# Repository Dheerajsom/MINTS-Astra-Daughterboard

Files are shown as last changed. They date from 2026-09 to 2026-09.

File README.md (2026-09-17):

# MINTS-Astra-Daughterboard

120 × 80 mm, four-layer EC Sense gas-sensor I2C daughterboard, revision B. The project contains the editable KiCad schematic and PCB, local component libraries, manufacturing files, assembly data, source scripts, reference documents, and verification reports.

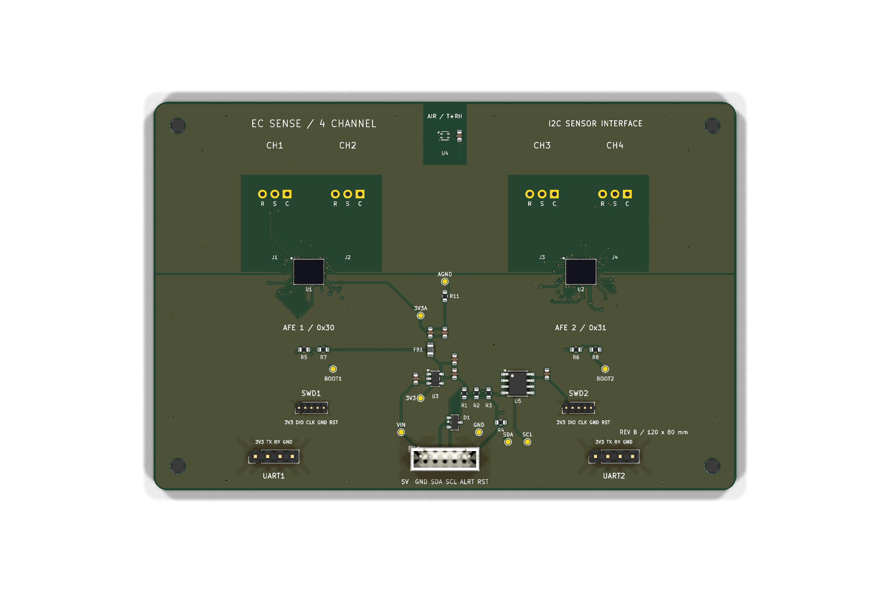
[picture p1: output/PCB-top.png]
Completed PCB, top view


## Open the design

Open [`ECSense_4CH_I2C.kicad_pro`](ECSense_4CH_I2C.kicad_pro) in KiCad 10. The project uses local footprint and 3D-model paths. The schematic and board retain their original `ECSense_4CH_I2C` filenames so project references remain intact.

Read [`PCB_README.md`](PCB_README.md) for electrical corrections, connector pinouts, assembly requirements, and bring-up instructions.

## Files

| Location | Contents |
| --- | --- |
| [`ECSense_4CH_I2C.kicad_pcb`](ECSense_4CH_I2C.kicad_pcb) | Completed routed PCB |
| [`ECSense_4CH_I2C.kicad_sch`](ECSense_4CH_I2C.kicad_sch) | Revision B schematic |
| [`ECGAS.pretty/`](ECGAS.pretty), [`libraries/`](libraries), [`models/`](models) | Local footprints and available 3D models |
| [`manufacturing/gerbers/`](manufacturing/gerbers) | Four copper layers, masks, silkscreens, pastes, outline, and drill files |
| [`manufacturing/assembly/`](manufacturing/assembly) | BOM and placement CSVs |
| [`Fabrication and assembly drawings`](output/pdf/Fabrication_and_assembly.pdf) | Mechanical, assembly, and drill drawings |
| [`Schematic PDF`](ECSense_4CH_I2C.pdf) | Printable schematic |
| [`output/`](output) | Board previews and final drawings |
| [`verification/`](verification) | Final checks plus development and routing records |
| [`scripts/`](scripts) | Construction, routing, and export scripts |
| [`sources/`](sources) | Manufacturer reference documents |

Download the [`complete project ZIP`](EC-Sense-120x80-Project.zip) or [`fabrication Gerbers ZIP`](manufacturing/EC-Sense-120x80-Gerbers.zip). The complete project ZIP is the compact release package; this repository also includes supporting development files.

## Verification and fabrication

The final KiCad 10.0.5 checks recorded **0 DRC violations, 0 unconnected items, 0 schematic parity discrepancies, and 0 ERC violations**. See [`final-drc.rpt`](verification/final-drc.rpt), [`final-erc.rpt`](verification/final-erc.rpt), and [`release-summary.json`](verification/release-summary.json). Earlier reports in `verification/` record intermediate work; the `final-*` reports describe the delivered board.

Specify four copper layers, nominal 1.6 mm FR-4, ENIG, and a fabricator supporting **0.075 mm trace/clearance and 0.20 mm via drills with 0.40 mm pads**. Read the full [fabrication notes](manufacturing/FABRICATION_NOTES.txt) before ordering.

This is a hardware prototype. Application firmware, gas-sensor calibration, and physical bench testing are required before use.

## Development records

The saved revision B KiCad project and `PCB_README.md` are authoritative. `DESIGN.md`, the original generator, and intermediate routing files document earlier stages. Construction scripts can overwrite completed routing; review them before running them. Local automatic backups, temporary files, editor state, and caches are ignored by Git.

Third-party KiCad library notices are included in [`libraries/LICENSE.md`](libraries/LICENSE.md) and [`models/kicad/LICENSE.md`](models/kicad/LICENSE.md).

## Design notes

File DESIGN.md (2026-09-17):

> **Revision B PCB update:** Read [PCB_README.md](PCB_README.md) for corrected pinouts, component values, socket selection, power range and bring-up requirements. Several assumptions in this original architecture note were incorrect. The corrected schematic and PCB are authoritative.

# 4-Channel EC Sense Gas Sensor Board with a Single I²C Bus

Design note + KiCad schematic for a custom carrier that takes four **bare ES1 3-pin
electrochemical sensors** and presents all their data on one I²C bus.

Source datasheets (in this folder):
`ES1-AG1-200-01 All Gas Sensor_Datasheet_V1.4_20250306.pdf`,
`TB600B&C-IAQ_Datasheet_V3.0_20250904.pdf`,
`EC Sense Product List_V1.9_20250409.pdf`.

---

## 1. What the datasheets actually give you

### 1.1 Bare sensor — ES1 series (the 3-pin part)

From the ES1-AG1-200-01 datasheet:

| Parameter | Value | Design consequence |
|---|---|---|
| Operating principle | Amperometric, **3-electrode** | Needs a potentiostat, not just an ADC |
| Pins (bottom view) | **C, S, R** in line — Counter, Sense (working), Reference | 3 pins, 2.54 mm pitch, Ø0.4 mm, body ~11.5 × 11.5 × 5.6 mm |
| Bias voltage | **0 mV** | V_BIAS = V_ZERO for this part; other gases may differ |
| Recommended load resistor | **100 Ω** | Set the AFE's R_LOAD to 100 Ω |
| Sensitivity | **40 nA/ppm ± 10** (CO cal), 55 nA/ppm ± 15 (isobutene cal) | 200 ppm FS → **8 µA**; 1000 ppm overload → 40 µA |
| Zero current | **± 100 nA** | = ±2.5 ppm equivalent. Zeroing in clean air is mandatory, not optional |
| Resolution | 0.1 ppm quoted "16-bit ADC" | 0.1 ppm ≈ 4 nA — well inside a decent TIA+ADC |
| Response | T50 < 10 s, T90 < 30 s | 1–4 Hz output rate is plenty; use the rest for averaging |
| Warm-up | < 60 s | |
| Temperature curve | ≈ **4 nA/ppm at −40 °C → ≈ 51 nA/ppm at +50 °C** | ~12× swing. **On-board temperature measurement and compensation is compulsory** |
| Long-term drift | < 5 %/year, life > 3 years | Recalibration/cartridge-swap plan needed |
| Storage | 0–20 °C (optimum 4–6 °C), 12 months | Keep spares refrigerated; ship with the electrode shorting clip fitted |

Two things worth flagging before you commit to a BOM:

- **AG1 "All Gas" is deliberately non-selective.** The cross-sensitivity table shows
  CO reads 105 ppm for a 100 ppm test, H₂ reads 625 ppm for 2000 ppm, AsH₃ reads 4 ppm
  for a 1 ppm calculated concentration, and NO₂/O₃ read *negative*. Four AG1 sensors will
  not give you four gases — populate the four sockets with gas-specific ES1 parts
  (CO, H₂S, NO₂, SO₂, NH₃, O₃, HCHO, …) from the product list.
- **O₂ (`01-ES1-O2-25%-01`) is electrically different** from the amperometric parts.
  If you need O₂, treat it as a separate channel variant, not a drop-in.

### 1.2 Ready-made module — TB600B/C (the "breakout board")

The TB600B&C is EC Sense's own breakout: the ES1 sensor + a microcontroller + a
temperature/humidity sensor + a flash chip holding the factory calibration, on a
23 × 25.5 × 9.5 mm board with a 4-pin cable.

| Parameter | Value |
|---|---|
| Output | UART TTL 3.3 V **or** I²C 3.3 V (separate part numbers, `…-I2C-01`) |
| I²C pinout | VCC = red, GND = black, **SDA = yellow, SCL = green** |
| **I²C clock** | **≤ 20 kHz** |
| Supply | 3.3–5.5 V, 5 V recommended; ~3.4–6.2 mA (I²C, LED off / peak) |
| Sleep | 0.9 mA @ 5 V |
| On-board T/RH | ±0.2 °C, ±2 % RH |
| Protocol | Q&A mode by default, switchable to active-upload |

**Why this pushes you toward your own board.** The datasheet publishes no address-select
pin and no address-configuration command, and the bus is limited to 20 kHz. Multiple
TB600-I2C modules on one bus will therefore collide. Your options with the stock modules
are a **TCA9548A I²C mux** (one module per channel) or an **LTC4316 address translator**
per module — both of which mean you are still paying for four microcontrollers, four
T/RH sensors and ~100 mm² each, to end up with a 20 kHz bus.

> **Plan B, if you want something working next week:** 4 × `04-TB600x-<gas>-<range>-I2C-01`
> behind a TCA9548A, 5 V rail, host talks to 0x70 then to the module. Zero analog design
> risk. Take this path for the first prototype if the science matters more than the board.

The rest of this document is **Plan A**: your own carrier around the bare ES1.

---

## 2. What the front end has to do

Per channel:

1. Hold the **reference electrode** at a programmed potential relative to the working
   electrode (0 mV for most EC Sense parts) — i.e. a potentiostat with a control
   amplifier driving the counter electrode.
2. Convert the working-electrode current to voltage with a **transimpedance amplifier**,
   with a settable R_LOAD of 100 Ω in series with the working electrode.
3. Digitise it with enough resolution that the **LSB is well under the sensor noise**.

Numbers, using 40 nA/ppm:

| Sensor | FS current | R_TIA | TIA FS | ADC LSB (16-bit over ±0.9 V) | ppm/LSB |
|---|---|---|---|---|---|
| ES1-AG1-**200** | 8.0 µA | 100 kΩ | 0.80 V | 27.5 µV → 0.275 nA | **0.0069 ppm** |
| ES1-AG1-**10** | 400 nA | 512 kΩ | 0.205 V | 27.5 µV → 0.054 nA | **0.0013 ppm** |
| ES1-CO-**1000** | 40 µA | 20 kΩ | 0.80 V | 27.5 µV → 1.4 nA | 0.034 ppm |

So a 16-bit ADC behind a programmable TIA comfortably beats the datasheet's own
0.01 ppm / 0.1 ppm resolution figures. **The limit is not the LSB — it is the ±100 nA
zero current, the 5 %/year drift and the 12× temperature coefficient.** Budget your
effort accordingly: the analog design is the easy part, the calibration is not.

Since R_TIA is switchable at runtime on the chosen part, implement **autoranging**:
drop to a low gain when a channel saturates (the ES1 overload range is 5× full scale)
and report the range in the status register.

---

## 3. IC options

| Role | Part | Key numbers | Verdict |
|---|---|---|---|
| **Potentiostat + ADC + MCU, 2 ch** | **ADuCM355** (ADI) | 2 potentiostats, LPTIA R_TIA 1 k–512 kΩ, R_LOAD 10/30/50/100/1.5k/3k/3.5k Ω, 16-bit 400 kSPS ADC, dual 12-bit bias DACs 0.2–2.4 V, EIS 0.016 Hz–200 kHz, Cortex-M3 26 MHz / 128 kB flash, UART+I²C+SPI, 72-LGA 6×5 mm, 2.8–3.6 V, 4.75–5.2 mA active / 3 µA hibernate | **Chosen.** One part does the whole channel, each device is its own I²C target, and EIS gives you sensor-health diagnostics for free |
| Potentiostat AFE, **4 ch**, no MCU | MAX30134 (ADI/Maxim) | 4 DC channels + 1 EIS channel, 4 × 16-bit current ADCs, 4 × 12-bit DACs, 3.5 µA bias current, 25-bump WLP 2.93 × 2.93 mm, ~$5.45/1k, **SPI only** | Strongest alternative — one chip for all four channels, half the cost. Costs you an external MCU and 0.4 mm-pitch WLP assembly |
| Same analog core, AFE only | AD5941 / AD5940 | SPI, pair with STM32G0/L4/RP2350 | Use if you already have an MCU you like and want ADI's analog core |
| Cheap single-channel potentiostat | TI **LMP91000** / LMP91002 | R_TIA 2.75 k–350 kΩ, internal bias 1–24 % of V_REF, I²C **for configuration only**, analog V_OUT, fixed address 0x48 with an **MENB** pin so several can share a bus | The classic budget option; needs an external ADC and 4 chip-selects |
| Precision I²C ADC (if using LMP91000) | TI ADS122C04 (24-bit, 2 diff ch, PGA), TI ADS1115 (16-bit, 4 ch, 4 addr), Microchip MCP3424 (18-bit, 4 ch, 8 addr) | | ADS122C04 if you care about noise, ADS1115 if you care about price |
| Discrete potentiostat | MCP6V51 (5 µV offset), LTC6078, ADA4505-2, LMP7721 (3 fA I_B), ADA4530-1 (fA) | | Only if you want full control of the loop and low-leakage input |
| I²C mux (address collisions) | TCA9548A / PCA9548A | 8 channels, 0x70–0x77 | Required for the TB600-I2C route |
| I²C address translator | LTC4316 | remaps a fixed-address target | Alternative to a mux |
| Level translation | PCA9306, TXS0102 | | If the host is 1.8 V |
| Bus extension | LTC4311 (active pull-up), PCA9515A | | If the sensor head is on a cable |
| T / RH | **SHT45-AD1B** (0x44), SHT40, or TMP117 | ±0.1 °C / ±1.0 % RH | Mandatory for compensation |
| ID + cal store | **24AA02E48** (0x50, EUI-48 at 0xFA) | | Board serial + per-sensor cal blob |
| Analog LDO | **ADP151AUJZ-3.3** | 9 µV_rms, 200 mA | Clean rail for the AFE |
| ESD | PESD3V3L2BT, TPD2E007 | | On SDA/SCL |
| Sensor socket | Mill-Max **0350 / 0305** series press-fit receptacles, or a 3-way SIP strip (Mill-Max 801/851 series, Preci-Dip 801-87-003) | accept 0.30–0.51 mm pins | Confirm against the Ø0.4 mm ES1 pin |

### Why ADuCM355 over MAX30134 here

You asked for a smart node per sensor, which the ADuCM355 gives you directly: firmware,
calibration and linearisation live next to the analog, the host sees clean ppm numbers,
and each device is an independent I²C target so a channel failure does not take the bus
down. It is also a hand-solderable LGA rather than a 0.4 mm WLP. The trade is cost
(~2 × ADuCM355 vs 1 × MAX30134) and firmware effort — you are writing an I²C target
driver, not just reading registers.

---

## 4. Chosen architecture

```
   ES1 socket J1 ──C/S/R──┐
                          ├── ADuCM355 U1  (pot 0, pot 1)  ──┐
   ES1 socket J2 ──C/S/R──┘        I²C target 0x30           │
                                                             ├── SDA / SCL ── host (J5)
   ES1 socket J3 ──C/S/R──┐                                  │      + /ALERT, /RESET
                          ├── ADuCM355 U2  (pot 0, pot 1)  ──┤
   ES1 socket J4 ──C/S/R──┘        I²C target 0x31           │
                                                             │
                     SHT45 (0x44) ───────────────────────────┤
                     24AA02E48 (0x50) ───────────────────────┘
```

- Both ADuCM355 run **the same firmware image**; each reads a strap resistor on **P2.4**
  at boot (U1 → 0 Ω to GND → 0x30, U2 → 10 kΩ to +3V3 → 0x31).
- One shared open-drain **/ALERT** (GPIO0 on both devices) for threshold alarms, so the
  host does not have to poll.
- **/RESET** is bussed to both devices and brought out to the host connector.
- Programming: SWD per device (J6, J7); **BM/P1.1** pulled up with a test point —
  pulling it low during reset drops the part into a loop so a bad image can be erased
  over SWD. UART on J8/J9 for logging and the serial bootloader.
- Analog rail **+3V3A** is ferrite-isolated from the digital +3V3; **AGND** and **GND**
  meet at a single 0 Ω (R11) under U1.
- **RCAL = 200 Ω, 0.1 %, ≤10 ppm/°C** per device (between RCAL0 and RCAL1) — this is the
  reference the EIS engine calibrates against.

### Per-channel passives (all four channels identical)

| Part | Value | Function |
|---|---|---|
| C_CE | 100 nF | CE ↔ CAP_POT, potentiostat loop compensation |
| C_RC | 100 nF | between RCx_0 and RCx_1, LPTIA filter |
| C_LPF | 4.7 µF | on AIN4_LPF0 / AIN7_LPF1 |
| C_VBIAS | 100 nF | VBIAS decoupling |
| C_VZERO | 100 nF (DNP) | optional, fit per ADI reference design |
| 3 × 22 pF C0G | — | CE / SE / RE to AGND, at the socket, EMC |
| JP (DNP) | — | SE–RE shorting jumper for storage/transport only |

---

## 5. Firmware: suggested I²C register map

8-bit register address, auto-increment, MSB-first, repeated-start for reads.

| Addr | R/W | Bytes | Contents |
|---|---|---|---|
| 0x00 | R | 1 | `WHO_AM_I` = 0xEC |
| 0x01 | R | 1 | `STATUS`: bit0 ch0 ready, bit1 ch1 ready, bit2 ch0 overrange, bit3 ch1 overrange, bit4 warm-up, bit7 fault |
| 0x02 | RW | 1 | `CTRL`: bit0 ch0 enable, bit1 ch1 enable, bit2 start EIS, bit6 sleep, bit7 soft reset |
| 0x03 | RW | 1 | `ODR` (0 = 1 Hz, 1 = 2 Hz, 2 = 4 Hz) |
| 0x10 | R | 4 | CH0 electrode current, int32, **pA** |
| 0x14 | R | 4 | CH0 concentration, int32, **ppb** (temperature-compensated) |
| 0x18 | R | 4 | CH1 electrode current, int32, pA |
| 0x1C | R | 4 | CH1 concentration, int32, ppb |
| 0x20 | R | 2 | Die temperature, int16, 0.01 °C |
| 0x22 | RW | 2 | Ambient temperature written by host (or read from SHT45), int16, 0.01 °C |
| 0x24 | RW | 2 | Ambient RH, uint16, 0.01 %RH |
| 0x30 | RW | 1 | CH0 R_TIA index (0 = auto) |
| 0x31 | RW | 1 | CH1 R_TIA index |
| 0x32 | RW | 2 | CH0 V_BIAS, uint16, DAC code |
| 0x34 | RW | 2 | CH1 V_BIAS |
| 0x40 | RW | 16 | CH0 sensor ID string |
| 0x50 | RW | 4 | CH0 sensitivity, nA/ppm × 1000 |
| 0x54 | RW | 4 | CH0 zero current, pA |
| 0x58 | RW | 4 | CH0 temperature-compensation polynomial coefficients |
| 0x70 | R | 8 | Last EIS result: R_s, C_dl (sensor-health indicator) |
| 0x7E | RW | 1 | `SAVE_CAL` — write 0xA5 to commit cal to flash |

Temperature compensation: store the ES1 curve as a 3rd-order polynomial in T normalised
to 25 °C, `S(T) = S₂₅ · (a₀ + a₁·ΔT + a₂·ΔT² + a₃·ΔT³)`, fitted to the curve on page 3 of
the ES1 datasheet, then refined against your own chamber data. Do **not** use a single
%/°C coefficient — the curve is strongly non-linear below 0 °C.

---

## 6. Layout rules that actually matter

The working-electrode node carries hundreds of picoamps to a few microamps. Leakage,
not noise, is what will ruin it.

1. **Guard ring** around every SE net and its via/pad, driven at V_ZERO (not AGND), on
   both the top layer and the layer directly beneath.
2. Keep SE traces **short (< 15 mm), on one layer, no vias**. Route CE and RE beside
   them, never crossing a digital net.
3. **No solder-mask opening** under the sockets other than the pads. Assemble with
   no-clean flux and clean anyway; ionic residue between SE and AGND at 10¹¹ Ω is a
   0.03 ppm offset.
4. 4-layer stack: L1 AFE + signal, L2 solid GND, L3 +3V3 / +3V3A (split, not overlapping
   the AFE), L4 digital.
5. Do **not** route I²C, SWD or the DC-DC flying-cap nets under the AFE section of U1/U2.
6. AGND and DGND join at **one** point (R11) under the device; AGND pour covers only the
   AFE corner.
7. Put the **SHT45 in the middle of the four sockets**, thermally coupled to them, with a
   routed slot isolating it from the LDO and the MCU dies. It is measuring *the sensors'*
   temperature, not the board's.
8. Keep the LDO and any heat source at the opposite end of the board. A 1 °C gradient
   across the sensor cluster is a ~2.5 % reading error at room temperature.
9. Conformal-coat the board **except** the socket area and the sensor apertures. Never
   let alcohol, acetone or strong solvent near the sensors (explicit datasheet warning).

---

## 7. BOM (4 channels)

| Qty | Ref | Part | Description |
|---|---|---|---|
| 2 | U1, U2 | ADUCM355BCCZ | Dual potentiostat + 16-bit ADC + Cortex-M3, 72-LGA |
| 1 | U3 | ADP151AUJZ-3.3 | 3.3 V 200 mA ultra-low-noise LDO, TSOT-23-5 |
| 1 | U4 | SHT45-AD1B | T/RH sensor, I²C 0x44 |
| 1 | U5 | 24AA02E48T-I/SN | 2 kbit EEPROM with EUI-48, I²C 0x50 |
| 4 | J1–J4 | 3 × Mill-Max 0350-series receptacle (or 1 × 3-way SIP socket) | EC Sense ES1 socket, 2.54 mm, Ø0.4 mm pin |
| 1 | J5 | JST PH B6B-PH-K | Host: VIN, GND, SDA, SCL, /ALERT, /RESET |
| 2 | J6, J7 | 1×5 1.27 mm header | SWD |
| 2 | J8, J9 | 1×4 2.54 mm header | UART / serial bootloader |
| 1 | D1 | PESD3V3L2BT | ESD array on SDA/SCL |
| 1 | FB1 | 600 Ω @ 100 MHz, 0805 | +3V3 → +3V3A |
| 2 | R (RCAL) | 200 Ω, 0.1 %, ≤10 ppm/°C | EIS calibration |
| 2 | R | 2.2 kΩ | I²C pull-ups |
| 3 | R | 10 kΩ | /ALERT, /RESET, U2 address strap |
| 2 | R | 10 kΩ | BM pull-ups |
| 1 | R | 0 Ω | U1 address strap (→ 0x30) |
| 1 | R11 | 0 Ω | AGND–GND single-point tie |
| 12 | C | 22 pF C0G | Electrode EMC filters (3 per channel) |
| 8 | C | 100 nF X7R | C_CE, C_VBIAS (2 per channel) |
| 4 | C | 100 nF X7R | C_RC (1 per channel) |
| 4 | C | 4.7 µF X7R | C_LPF (1 per channel) |
| 4 | C | 100 nF (DNP) | C_VZERO |
| ~20 | C | 100 nF / 1 µF / 4.7 µF | Supply, regulator and DC-DC decoupling — **values per ADuCM355 datasheet Applications Information** |
| 4 | JP1–JP4 | Solder jumper (DNP) | SE–RE storage short |

---

## 8. KiCad 10 project

Everything is written in the **native KiCad 10 format** — not a KiCad 7 file that
KiCad 10 upgrades on open. The schematic is `version 20260306`
(`generator_version "10.0"`), the symbol library is `version 20251024`, and the project
file uses `meta.version 3` / `net_settings.meta.version 5`. All of it was produced and
checked with KiCad **10.0.6**.

### `ECSense_4CH_I2C/`

| File | What it is |
|---|---|
| `ECSense_4CH_I2C.kicad_pro` | Project file, `Default` / `SENSOR` / `POWER` net classes pre-created |
| `ECSense_4CH_I2C.kicad_sch` | A1 schematic, 198 symbols |
| `ECGAS.kicad_sym` | The 19 custom symbols as a real, editable library |
| `sym-lib-table` | Registers `ECGAS` against `${KIPRJMOD}/ECGAS.kicad_sym` |
| `fp-lib-table` | Registers `ECGAS.pretty` for the two custom footprints |
| `ECGAS.pretty/README.md` | Dimensions and guidance for the two footprints you still have to draw |
| `ECSense_4CH_I2C.pdf` / `.svg` | Schematic plots, exported by KiCad |
| `ECSense_4CH_I2C.net` | KiCad netlist |
| `ECSense_4CH_I2C-bom.csv` | BOM, exported by KiCad |
| `erc.rpt` | The ERC report as it stands |

Build scripts, at the top level:

| File | What it is |
|---|---|
| `gen_sch.py` | Generates the schematic — edit the constants at the top to change channel count, spacing or net names |
| `verify_sch.py` | Connectivity checker: duplicate refdes, dangling labels/wires, single-pin nets, off-grid points, **and T-junctions** |
| `make_symlib.py` | Extracts the embedded symbols into `ECGAS.kicad_sym` |
| `build_kicad10.sh` | Runs the whole chain: generate → check → extract library → upgrade to KiCad 10 → ERC + PDF + SVG + netlist + BOM |

Rebuild with:

```sh
KICAD_CLI=/path/to/kicad-cli ./build_kicad10.sh
```

`gen_sch.py` writes the older s-expression dialect and `build_kicad10.sh` calls
`kicad-cli sch upgrade` / `sym upgrade` to convert — so the format conversion is always
done by KiCad itself rather than by hand.

### Two real shorts that KiCad 10's ERC caught

Running proper ERC found bugs that a syntax check would never have shown. Both were the
same mistake: **a wire routed straight through another wire's endpoint**, which KiCad
treats as a connection.

1. **The entire I²C bus was shorted to GND.** At J5, the GND pin's drop wire ran down
   past the SDA and SCL stubs at exactly the x they ended on. SDA, SCL and GND became
   one net — the board would have been dead on arrival with no obvious cause.
2. **AGND was shorted to GND at both ADuCM355s.** The AGND rail dropped onto the DGND
   rail's horizontal run, merging the analog and digital grounds and making the R11
   single-point tie meaningless — which would have quietly undone the grounding scheme
   in section 6.
3. A third instance at the EEPROM: the `WP` pull-down ran through the SDA and SCL stubs.

`verify_sch.py` now models T-junctions (a point lying in the *interior* of a wire, not
just at its endpoints), so this class of error is caught before KiCad ever sees the file.

### Validation actually performed (KiCad 10.0.6)

```
kicad-cli sch upgrade          -> version 20260306, generator_version 10.0
kicad-cli sym upgrade          -> version 20251024, generator_version 10.0
kicad-cli sch erc              -> 6 violations, ALL of them the two footprints
                                  still to be drawn (4 x ES1 socket, 2 x ADuCM355 LGA).
                                  Zero pin_to_pin, zero multiple_net_names,
                                  zero power_pin_not_driven, zero dangling.
kicad-cli sch export netlist   -> 83 nets, every one with >= 2 nodes
kicad-cli sch export pdf/svg   -> OK
kicad-cli sch export bom       -> OK
verify_sch.py                  -> no duplicate refdes, no dangling labels or wires,
                                  no single-pin nets, 0 T-junctions, all on 1.27 mm grid
```

Netlist spot-check, confirming the buses are separate and the sensor wiring is right:

```
SDA       7  D1.1  J5.3  R1.2  U1.H5  U2.H5  U4.1  U5.5
SCL       7  D1.3  J5.4  R2.2  U1.J5  U2.J5  U4.4  U5.6
GND      29   (separate from AGND)
AGND     41   (separate from GND, tied only through R11)
+3V3A     7  C36.1 C37.1 FB1.2 U1.F11 U1.G2 U2.F11 U2.G2
~{ALERT}  4  J5.5  R3.2  U1.G10 U2.G10
/CH1_CE   4  C1.1  C4.1  J1.1(C)  U1.A1(CE0)
/CH4_SE   4  C26.1 J4.2(S) JP4.1  U2.A9(SE1)
```

## 9. Verify before you fabricate

1. **ADuCM355 pinout.** The pin numbers in the schematic were transcribed from the
   Rev. C datasheet pin table. Two assignments (B1 = RE0, B2 = VZERO0) were reconstructed
   from the symmetry of the channel-1 pins, not read directly. **Check all 72 pins against
   the official PDF and the EVAL-ADUCM355QSPZ reference schematic.**
2. **DC-DC and regulator capacitors.** VDCDC_CAP1P/1N/2P/2N/CAPOUT, AVDD_REG, DVDD_REG,
   DVDD_REG_AD values in the schematic are placeholders. Take them from the datasheet.
3. **ES1 socket.** Confirm the Ø0.4 mm pin diameter and 2.54 mm pitch against the
   mechanical drawing of *your* part numbers, and against the socket's pin-acceptance range.
   Then draw `ECGAS:EC_Sense_ES1_3pin_2.54mm` and `ECGAS:ADuCM355_LGA-72_6x5mm` — these are
   the only two footprints not resolved by the standard KiCad 10 libraries, and the only
   two ERC violations left in `erc.rpt`. See `ECGAS.pretty/README.md`.
4. **Bias per gas.** The ES1-AG1 is 0 mV. Confirm with EC Sense for each gas variant you
   intend to use before fixing the V_BIAS default in firmware.
5. **I²C target mode.** Confirm the ADuCM355 I²C peripheral supports clock stretching in
   target mode at the speed your host runs, and that your host tolerates it.
6. **Bench check the TIA before trusting it.** Drive a known current into a socket
   (a precision voltage source through a 1 GΩ resistor gives clean nanoamps) and verify
   gain and linearity at each R_TIA setting. Then zero in clean air / N₂ and span with
   certified gas.

---

## Sources

- [ADuCM355 product page, Analog Devices](https://www.analog.com/en/products/aducm355.html)
- [ADuCM355 datasheet (Rev. C)](https://www.analog.com/media/en/technical-documentation/data-sheets/aducm355.pdf)
- [ADuCM355 Hardware Reference Manual UG-1262](https://www.analog.com/media/en/technical-documentation/user-guides/aducm355-hardware-reference-manual-ug-1262.pdf)
- [MAX30131/MAX30132/MAX30134 electrochemical sensor AFEs](https://www.analog.com/en/products/max30134.html)
- [MAX30131/32/34 datasheet](https://www.analog.com/media/en/technical-documentation/data-sheets/max30131-max30132-max30134.pdf)
- [AD5941 analog front end](https://www.analog.com/en/products/ad5941.html)
- [AD5940 analog front end](https://www.analog.com/en/products/ad5940.html)
- [AN-2058: ADuCM355 User Bootloader](https://www.analog.com/en/resources/app-notes/an-2058.html)
- EC Sense `ES1-AG1-200-01 All Gas Sensor_Datasheet_V1.4_20250306.pdf` (local)
- EC Sense `TB600B&C-IAQ_Datasheet_V3.0_20250904.pdf` (local)
- EC Sense `EC Sense Product List_V1.9_20250409.pdf` (local)

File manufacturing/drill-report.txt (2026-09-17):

Drill report for ECSense_4CH_I2C.kicad_pcb
Created on 2026-09-16T20:36:38

Copper Layer Stackup:
    =============================================================
    L1 :  F.Cu                      front
    L2 :  In1.Cu                    in1
    L3 :  In2.Cu                    in2
    L4 :  B.Cu                      back

Drill file 'ECSense_4CH_I2C-PTH.drl' contains
    plated through holes:
    =============================================================
    T1  0.200mm  0.0079"  (161 holes))
    T2  0.300mm  0.0118"  (19 holes))
    T3  0.650mm  0.0256"  (10 holes))
    T4  0.750mm  0.0295"  (6 holes))
    T5  1.000mm  0.0394"  (20 holes))

    Total plated holes count 216

Drill file 'ECSense_4CH_I2C-NPTH.drl' contains
    unplated through holes:
    =============================================================
    T1  3.200mm  0.1260"  (4 holes))

    Total unplated holes count 4

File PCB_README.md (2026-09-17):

# EC Sense four-channel I2C PCB — revision B

120 × 80 mm outline, R3 corners, four M3 mounting holes on a 110 × 70 mm pattern. Four copper layers, nominal 1.6 mm FR-4. This is a hardware prototype: the ADuCM355 devices require application firmware and each installed gas sensor requires calibration. Design-rule checking is not a substitute for a powered bench test.

Open `ECSense_4CH_I2C.kicad_pro` in KiCad 10. The PCB, corrected schematic, footprint libraries, manufacturing outputs and verification reports are supplied together. The original schematic and generator are preserved in the working folder's `.history/pre-pcb*`, outside the release archive.

## Completed layout and checks

Final KiCad 10.0.5 checks: **0 DRC violations, 0 unconnected items, 0 schematic parity discrepancies, and 0 ERC violations**. No individual DRC exclusions are used. The checked board contains 109 footprints (96 schematic components, 4 mounting holes and 9 test pads), 1,309 track segments and 180 through vias. Check reports are in `verification/final-drc.*` and `verification/final-erc.*`.

The four layers, from top to bottom, are F.Cu (components/signals/ground), In1.Cu (ground with local escape routing), In2.Cu (power pours/signals), and B.Cu (passives/signals/ground). Analog sensor regions have surface copper keepouts; the temperature/humidity sensor is away from the regulator. Analog and digital grounds meet through R11. Ground stitching connects the surface pours to the inner ground layer.

Deliverables:

- `ECSense_4CH_I2C.kicad_pro`, `.kicad_sch`, `.kicad_pcb`: editable project and design.
- `manufacturing/gerbers/`: four copper layers, masks, silkscreens, pastes, board profile, separate plated/nonplated drill files, and Gerber job file.
- `manufacturing/assembly/`: current BOM and placement CSVs. JP1-JP4 are the only DNP items; all capacitors are fitted.
- `output/pdf/Fabrication_and_assembly.pdf`: mechanical, front/back assembly and drill drawings.
- `ECSense_4CH_I2C.pdf`: updated revision B schematic.
- `output/PCB-top.png` and `output/PCB-bottom.png`: views of the completed layout.
- `manufacturing/EC-Sense-120x80-Gerbers.zip`: fabrication files only.
- `EC-Sense-120x80-Project.zip`: editable design, local libraries, outputs and final checks.

The final KiCad files are authoritative. Scripts in the working folder's `scripts/` record construction and routing iterations; running them again can replace completed routing. These iteration scripts are not included in the release archive.

## Electrical corrections made before layout

The original schematic contained errors beyond the missing footprints:

- U1/U2 channel 0: CE0 is B1; RE0 is A1.
- U4 SHT45: SDA=1, SCL=2, VDD=3, GND=4.
- D1 PESD3V3L2BT: signal pins 1/2, common ground pin 3.
- U1/U2 AVDD_DD (G2) now uses the digital 3.3 V rail as required by the pin table.
- Shared ALERT moved from GPIO0 to GPIO1 (H10). GPIO0 drives high after reset and is unsuitable for the original wired connection. Firmware must emulate open drain: assert low, release by selecting input; never drive high.
- Reference/regulator capacitors and DC/DC flying capacitors now follow ADuCM355 Rev C. VZERO capacitors are populated.
- Added one local 100 nF bypass per ADuCM355 supply pin, plus EEPROM bypass.
- 24AA02E48 pins 1/2/3/7 are marked NC, rather than presenting unused pins as address/write-protect controls.
- VIN is specified as 4.0–5.5 V, nominal 5 V, to allow headroom for the 3.3 V LDO.

## Manufacturing and assembly

Order 4 copper layers, nominal 1.6 mm FR-4, ENIG, solder mask and silkscreen on both sides. No controlled-impedance requirement is specified. The fabricator must support **0.075 mm (approximately 3 mil) minimum trace/clearance, 0.20 mm finished via drills with 0.40 mm pads and 0.10 mm annular rings**. Stitching vias use 0.30 mm drills / 0.60 mm pads. Minimum hole-to-hole spacing is 0.20 mm and copper-to-board-edge clearance is 0.30 mm. The 0.5 mm LGA package requires fine tracks near the processors; ordinary 6/6 mil service is insufficient. Use tented signal vias and inspect the LGA joints after reflow. Discuss the 0.25 mm LGA lands and an approximately 80 µm stencil with the assembler. Surface-mounted parts are on both sides. The board uses ordinary through vias, with no blind/buried vias or via-in-pad process.

All manufacturing and placement outputs use the same absolute KiCad origin. The outline centerline extends from (50, 50) to (170, 130) mm; the line width is a drawing stroke, not extra board material. The four 3.2 mm nonplated mounting holes are at (55,55), (165,55), (55,125), and (165,125) mm. The outer dimensions are exactly 120 x 80 mm, with 3 mm corner radii. Drill and placement outputs follow their file-format axis conventions. The assembly PDF shows the bottom side mirrored for viewing from below; do not mirror the Gerbers.

J1–J4 each accept **three Mill-Max 0548-0-15-15-21-27-10-0 receptacles**. Their #21 contact accepts 0.381–0.559 mm pins; the ES1 pins are 0.40 ±0.01 mm. Footprint holes are 1.00 mm finished plated diameter (manufacturer minimum 0.9144 mm), with 1.8 mm pads and 2.54 mm pitch. C/S/R is mirrored from the sensor's bottom-view drawing into the PCB top view. **The earlier suggestions of Mill-Max 0350 and 0305 are unsuitable for these small sensor pins.**

The sensor drawing does not dimension the pin-row offset within the body. A conservative 14 × 24 mm component courtyard reserves the full possible body envelope around the pin row; no guessed offset is needed for PCB fit. The 3D socket representation is illustrative, not a mating-part inspection model. Insert the gas sensors after soldering and cleaning. Do not expose the sensor apertures or SHT45 to solvents or conformal coating.

C1–C3, C9–C11, C17–C19 and C25–C27: C0G/NP0. Other small capacitors: X7R, preferably 10 V or higher; check effective capacitance under DC bias. R9/R10: 200 Ω, 0.1%, ≤10 ppm/°C. Fit all capacitors. Leave JP1–JP4 open during operation; they are only storage/transport shorts. R11 is the sole AGND–GND connection and must be populated.

## Connectors and bring-up

| Connector | Pin order |
|---|---|
| J5, JST PH 6-pin host | 1 VIN, 2 GND, 3 SDA, 4 SCL, 5 ALERT, 6 RESET |
| J6/J7, 1.27 mm SWD | 1 3V3 reference, 2 SWDIO, 3 SWCLK, 4 GND, 5 RESET |
| J8/J9, 2.54 mm UART | 1 3V3 reference, 2 MCU TX, 3 MCU RX, 4 GND |

All bus/debug signals are **3.3 V logic**. Supply through J5; the 3V3 debug pins are voltage references, not an additional power input. Program U1 and U2 independently using SWD. Their default addresses 0x30 and 0x31 are a firmware convention selected by the P2.4 straps, not fixed hardware addresses. U4 uses 0x44; U5 uses 0x50. BOOT test pads allow recovery by holding the corresponding BM pin low during reset.

Power up initially with a current-limited 5 V supply and no gas sensors. Check 3V3/3V3A and internal regulated/reference voltages, debug access, I2C, and the ALERT release state. Configure the potentiostats and gas-specific bias before insertion. Verify current measurement with a precision current source, then perform clean-air zero and certified-gas span calibration. Firmware, calibrated ppm conversion, environmental qualification and physical bench testing are not included in this PCB deliverable.

## Source drawings

- [Analog Devices ADuCM355 Rev C, pinout and recommended components](https://www.analog.com/media/en/technical-documentation/data-sheets/ADuCM355.pdf), pp. 20–23 and 26–28.
- [Sensirion SHT4x data sheet](https://sensirion.com/resource/datasheet/sht4x).
- [Nexperia PESD3V3L2BT](https://assets.nexperia.com/documents/data-sheet/PESD3V3L2BT.pdf).
- [Microchip 24AA02E48](https://ww1.microchip.com/downloads/en/DeviceDoc/22124C.pdf).
- [EC Sense ES1 mechanical drawing](https://ecsense.com/wp-content/uploads/2021/01/ES1-AG1-200-01-All-Gas-Sensor_Datasheet_V1.4_20250306.pdf).
- [Mill-Max receptacle catalog, p. 157](https://www.mill-max.com/sites/default/files/external/catalog/2020-03/153-201_0.pdf).

The earlier working-folder `DESIGN.md` is historical architecture context, outside the release archive. This file and the revision B schematic supersede conflicting pinout, capacitor, socket, power, and ALERT details in it.

Standard footprints and available 3D models are copied from the installed KiCad 10 libraries; see `libraries/LICENSE.md` and `models/kicad/LICENSE.md`. Local 3D model paths replace installation-specific paths. The custom ADuCM355 and socket bodies are illustrative; the SHT45 land pattern is supplied even though its installed KiCad 3D model is unavailable. Land patterns and manufacturer drawings govern assembly, not the rendering.

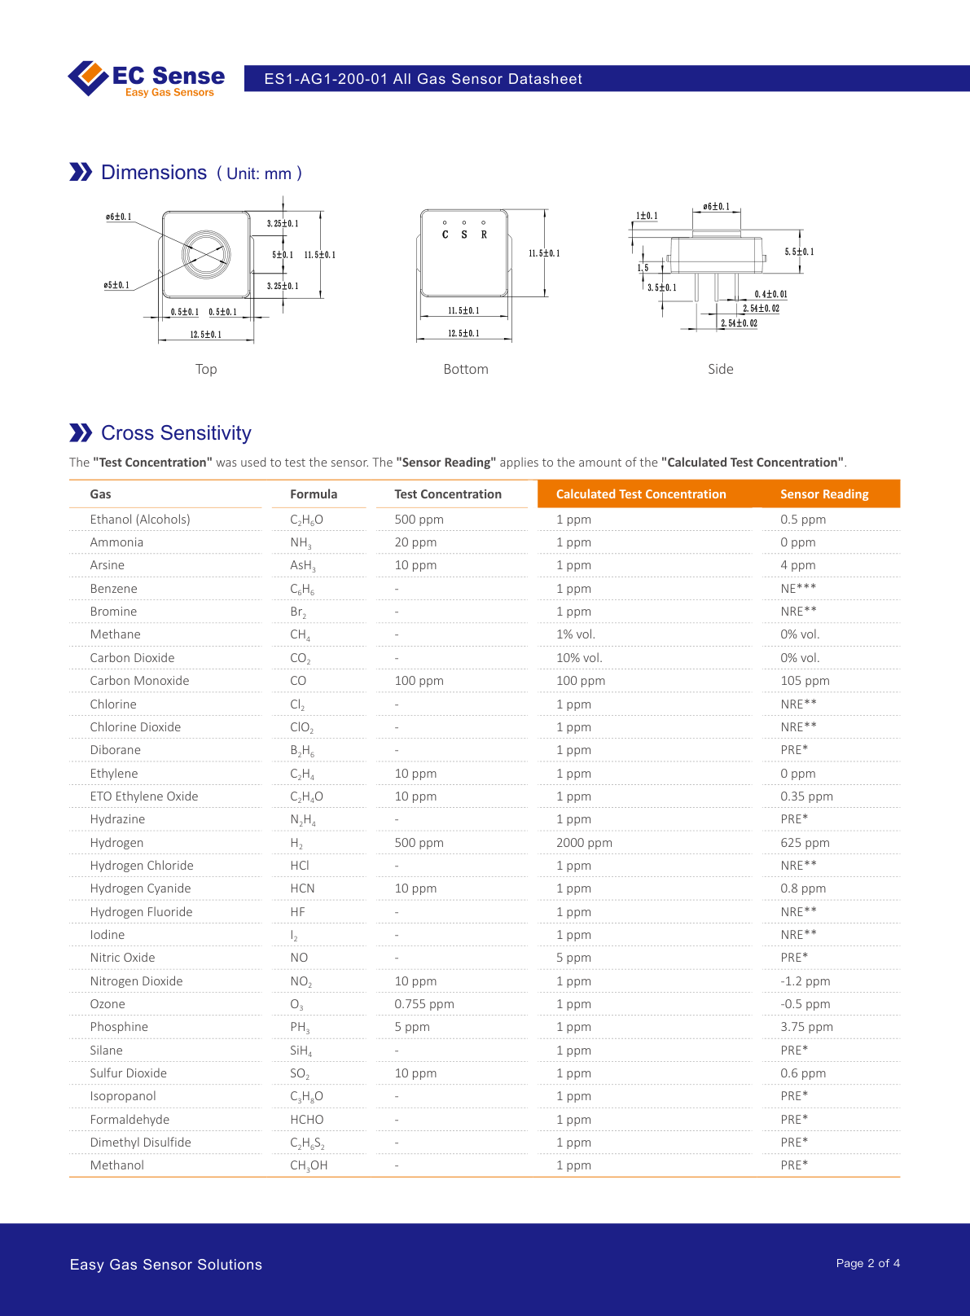
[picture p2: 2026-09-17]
verification/ES1-mechanical.png

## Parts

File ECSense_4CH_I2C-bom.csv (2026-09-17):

References | Value | Footprint | Quantity | DNP | Manufacturer_Part | Tolerance | Assembly_Note
C1 | 22p | Capacitor_SMD:C_0603_1608Metric | 1 |  |  | C0G 5% | EMC filter, keep at socket
C2 | 22p | Capacitor_SMD:C_0603_1608Metric | 1 |  |  | C0G 5% | EMC filter, keep at socket
C3 | 22p | Capacitor_SMD:C_0603_1608Metric | 1 |  |  | C0G 5% | EMC filter, keep at socket
C4 | 100n | Capacitor_SMD:C_0603_1608Metric | 1 |  |  |  | Potentiostat loop compensation, CE to CAP_POT
C5 | 100n | Capacitor_SMD:C_0603_1608Metric | 1 |  |  |  | LPTIA RC filter between RCx_0 and RCx_1
C6 | 4u7 | Capacitor_SMD:C_0603_1608Metric | 1 |  |  |  | LPTIA output low-pass, X7R 10V
C7 | 100n | Capacitor_SMD:C_0603_1608Metric | 1 |  |  |  | Required VZERO decoupling per ADuCM355 Rev C p26
C8 | 100n | Capacitor_SMD:C_0603_1608Metric | 1 |  |  |  | VBIAS decoupling
C9 | 22p | Capacitor_SMD:C_0603_1608Metric | 1 |  |  | C0G 5% | EMC filter, keep at socket
C10 | 22p | Capacitor_SMD:C_0603_1608Metric | 1 |  |  | C0G 5% | EMC filter, keep at socket
C11 | 22p | Capacitor_SMD:C_0603_1608Metric | 1 |  |  | C0G 5% | EMC filter, keep at socket
C12 | 100n | Capacitor_SMD:C_0603_1608Metric | 1 |  |  |  | Potentiostat loop compensation, CE to CAP_POT
C13 | 100n | Capacitor_SMD:C_0603_1608Metric | 1 |  |  |  | LPTIA RC filter between RCx_0 and RCx_1
C14 | 4u7 | Capacitor_SMD:C_0603_1608Metric | 1 |  |  |  | LPTIA output low-pass, X7R 10V
C15 | 100n | Capacitor_SMD:C_0603_1608Metric | 1 |  |  |  | Required VZERO decoupling per ADuCM355 Rev C p26
C16 | 100n | Capacitor_SMD:C_0603_1608Metric | 1 |  |  |  | VBIAS decoupling
C17 | 22p | Capacitor_SMD:C_0603_1608Metric | 1 |  |  | C0G 5% | EMC filter, keep at socket
C18 | 22p | Capacitor_SMD:C_0603_1608Metric | 1 |  |  | C0G 5% | EMC filter, keep at socket
C19 | 22p | Capacitor_SMD:C_0603_1608Metric | 1 |  |  | C0G 5% | EMC filter, keep at socket
C20 | 100n | Capacitor_SMD:C_0603_1608Metric | 1 |  |  |  | Potentiostat loop compensation, CE to CAP_POT
C21 | 100n | Capacitor_SMD:C_0603_1608Metric | 1 |  |  |  | LPTIA RC filter between RCx_0 and RCx_1
C22 | 4u7 | Capacitor_SMD:C_0603_1608Metric | 1 |  |  |  | LPTIA output low-pass, X7R 10V
C23 | 100n | Capacitor_SMD:C_0603_1608Metric | 1 |  |  |  | Required VZERO decoupling per ADuCM355 Rev C p26
C24 | 100n | Capacitor_SMD:C_0603_1608Metric | 1 |  |  |  | VBIAS decoupling
C25 | 22p | Capacitor_SMD:C_0603_1608Metric | 1 |  |  | C0G 5% | EMC filter, keep at socket
C26 | 22p | Capacitor_SMD:C_0603_1608Metric | 1 |  |  | C0G 5% | EMC filter, keep at socket
C27 | 22p | Capacitor_SMD:C_0603_1608Metric | 1 |  |  | C0G 5% | EMC filter, keep at socket
C28 | 100n | Capacitor_SMD:C_0603_1608Metric | 1 |  |  |  | Potentiostat loop compensation, CE to CAP_POT
C29 | 100n | Capacitor_SMD:C_0603_1608Metric | 1 |  |  |  | LPTIA RC filter between RCx_0 and RCx_1
C30 | 4u7 | Capacitor_SMD:C_0603_1608Metric | 1 |  |  |  | LPTIA output low-pass, X7R 10V
C31 | 100n | Capacitor_SMD:C_0603_1608Metric | 1 |  |  |  | Required VZERO decoupling per ADuCM355 Rev C p26
C32 | 100n | Capacitor_SMD:C_0603_1608Metric | 1 |  |  |  | VBIAS decoupling
C33 | 10u | Capacitor_SMD:C_0603_1608Metric | 1
C34 | 10u | Capacitor_SMD:C_0603_1608Metric | 1
C35 | 1u | Capacitor_SMD:C_0603_1608Metric | 1
C36 | 10u | Capacitor_SMD:C_0603_1608Metric | 1
C37 | 100n | Capacitor_SMD:C_0603_1608Metric | 1
C38 | 4u7 | Capacitor_SMD:C_0603_1608Metric | 1
C39 | 470n | Capacitor_SMD:C_0603_1608Metric | 1
C40 | 470n | Capacitor_SMD:C_0603_1608Metric | 1
C41 | 470n | Capacitor_SMD:C_0603_1608Metric | 1
C42 | 470n | Capacitor_SMD:C_0603_1608Metric | 1
C43 | 470n | Capacitor_SMD:C_0603_1608Metric | 1
C44 | 470n | Capacitor_SMD:C_0603_1608Metric | 1
C45 | 4u7 | Capacitor_SMD:C_0603_1608Metric | 1
C46 | 470n | Capacitor_SMD:C_0603_1608Metric | 1
C47 | 470n | Capacitor_SMD:C_0603_1608Metric | 1
C48 | 470n | Capacitor_SMD:C_0603_1608Metric | 1
C49 | 470n | Capacitor_SMD:C_0603_1608Metric | 1
C50 | 470n | Capacitor_SMD:C_0603_1608Metric | 1
C51 | 470n | Capacitor_SMD:C_0603_1608Metric | 1
C52 | 100n | Capacitor_SMD:C_0603_1608Metric | 1
C53 | 100n | Capacitor_SMD:C_0603_1608Metric | 1
C54 | 100n | Capacitor_SMD:C_0603_1608Metric | 1
C55 | 100n | Capacitor_SMD:C_0603_1608Metric | 1
C56 | 100n | Capacitor_SMD:C_0603_1608Metric | 1
C57 | 100n | Capacitor_SMD:C_0603_1608Metric | 1 |  |  |  | U1 AVDD local bypass
C58 | 100n | Capacitor_SMD:C_0603_1608Metric | 1 |  |  |  | U1 AVDD_DD local bypass
C59 | 100n | Capacitor_SMD:C_0603_1608Metric | 1 |  |  |  | U1 DVDD local bypass
C60 | 100n | Capacitor_SMD:C_0603_1608Metric | 1 |  |  |  | U1 DVDD_AD local bypass
C61 | 100n | Capacitor_SMD:C_0603_1608Metric | 1 |  |  |  | U2 AVDD local bypass
C62 | 100n | Capacitor_SMD:C_0603_1608Metric | 1 |  |  |  | U2 AVDD_DD local bypass
C63 | 100n | Capacitor_SMD:C_0603_1608Metric | 1 |  |  |  | U2 DVDD local bypass
C64 | 100n | Capacitor_SMD:C_0603_1608Metric | 1 |  |  |  | U2 DVDD_AD local bypass
C65 | 100n | Capacitor_SMD:C_0603_1608Metric | 1 |  |  |  | U5 local bypass
D1 | PESD3V3L2BT | Package_TO_SOT_SMD:SOT-23 | 1
FB1 | 600R@100MHz | Inductor_SMD:L_0805_2012Metric | 1
J1 | ES1 CH1 | ECGAS:EC_Sense_ES1_3pin_2.54mm | 1 |  | 3x Mill-Max 0350 series receptacle (0.30-0.51 mm pin) |  | EC Sense ES1 bare sensor, C/S/R, 2.54 mm pitch
J2 | ES1 CH2 | ECGAS:EC_Sense_ES1_3pin_2.54mm | 1 |  | 3x Mill-Max 0350 series receptacle (0.30-0.51 mm pin) |  | EC Sense ES1 bare sensor, C/S/R, 2.54 mm pitch
J3 | ES1 CH3 | ECGAS:EC_Sense_ES1_3pin_2.54mm | 1 |  | 3x Mill-Max 0350 series receptacle (0.30-0.51 mm pin) |  | EC Sense ES1 bare sensor, C/S/R, 2.54 mm pitch
J4 | ES1 CH4 | ECGAS:EC_Sense_ES1_3pin_2.54mm | 1 |  | 3x Mill-Max 0350 series receptacle (0.30-0.51 mm pin) |  | EC Sense ES1 bare sensor, C/S/R, 2.54 mm pitch
J5 | Host I2C + power | Connector_JST:JST_PH_B6B-PH-K_1x06_P2.00mm_Vertical | 1 |  |  |  | VIN 4.0-5.5 V; nominal 5 V
J6 | SWD U1 | Connector_PinHeader_1.27mm:PinHeader_1x05_P1.27mm_Vertical | 1
J7 | SWD U2 | Connector_PinHeader_1.27mm:PinHeader_1x05_P1.27mm_Vertical | 1
J8 | UART U1 | Connector_PinHeader_2.54mm:PinHeader_1x04_P2.54mm_Vertical | 1
J9 | UART U2 | Connector_PinHeader_2.54mm:PinHeader_1x04_P2.54mm_Vertical | 1
JP1 | SE-RE short | Jumper:SolderJumper-2_P1.3mm_Open_Pad1.0x1.5mm | 1 | DNP |  |  | Fit only for storage/transport. Remove before measurement.
JP2 | SE-RE short | Jumper:SolderJumper-2_P1.3mm_Open_Pad1.0x1.5mm | 1 | DNP |  |  | Fit only for storage/transport. Remove before measurement.
JP3 | SE-RE short | Jumper:SolderJumper-2_P1.3mm_Open_Pad1.0x1.5mm | 1 | DNP |  |  | Fit only for storage/transport. Remove before measurement.
JP4 | SE-RE short | Jumper:SolderJumper-2_P1.3mm_Open_Pad1.0x1.5mm | 1 | DNP |  |  | Fit only for storage/transport. Remove before measurement.
R1 | 2k2 | Resistor_SMD:R_0603_1608Metric | 1
R2 | 2k2 | Resistor_SMD:R_0603_1608Metric | 1
R3 | 10k | Resistor_SMD:R_0603_1608Metric | 1
R4 | 10k | Resistor_SMD:R_0603_1608Metric | 1
R5 | 0R | Resistor_SMD:R_0603_1608Metric | 1
R6 | 10k | Resistor_SMD:R_0603_1608Metric | 1
R7 | 10k | Resistor_SMD:R_0603_1608Metric | 1
R8 | 10k | Resistor_SMD:R_0603_1608Metric | 1
R9 | 200R 0.1% 10ppm | Resistor_SMD:R_0603_1608Metric | 1 |  |  |  | RCAL between RCAL0 and RCAL1, low tempco
R10 | 200R 0.1% 10ppm | Resistor_SMD:R_0603_1608Metric | 1 |  |  |  | RCAL between RCAL0 and RCAL1, low tempco
R11 | 0R | Resistor_SMD:R_0603_1608Metric | 1 |  |  |  | Single-point analog/digital ground tie, place under U1
U1 | ADuCM355 | ECGAS:ADuCM355_LGA-72_6x5mm | 1 |  | ADUCM355BCCZ
U2 | ADuCM355 | ECGAS:ADuCM355_LGA-72_6x5mm | 1 |  | ADUCM355BCCZ
U3 | ADP151AUJZ-3.3 | Package_TO_SOT_SMD:TSOT-23-5 | 1
U4 | SHT45-AD1B | Sensor_Humidity:Sensirion_DFN-4_1.5x1.5mm_P0.8mm_SHT4x_NoCentralPad | 1
U5 | 24AA02E48T-I/SN | Package_SO:SOIC-8_3.9x4.9mm_P1.27mm | 1

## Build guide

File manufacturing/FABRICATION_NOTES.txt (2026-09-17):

EC SENSE 4-CHANNEL I2C — REVISION B
BOARD: 120.00 x 80.00 mm, R3 corners; 4 copper layers; nominal 1.6 mm FR-4.
ORDER: ENIG; mask and silkscreen both sides; tent through vias.
CAPABILITY: 0.075 mm trace/clearance; 0.20 mm finished via holes, 0.40 mm pads.
Standard through vias only; no blind/buried vias or via-in-pad.
Four 3.20 mm NPTH mounting holes on a 110 x 70 mm pattern.
COPPER ORDER: F_Cu / In1_Cu / In2_Cu / B_Cu.
Use the Edge_Cuts centerline as the outline. All plots share the KiCad origin.
Do not mirror Gerbers. PTH and NPTH drills are separate.
Fine-pitch LGA assembly: discuss stencil and inspection with assembler.
See PCB_README.md in the project package for assembly and bring-up details.

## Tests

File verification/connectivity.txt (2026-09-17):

duplicate refdes: none
T-junctions (point on wire interior): 0

symbols placed: 221   distinct nets: 248
named nets: 78

no structural issues found.

--- net pin counts ---
  CH1_CAPPOT               2
  CH1_CE                   4
  CH1_LPF                  2
  CH1_RC0                  2
  CH1_RC1                  2
  CH1_RE                   4
  CH1_SE                   4
  CH1_VBIAS                2
  CH1_VZERO                2
  CH2_CAPPOT               2
  CH2_CE                   4
  CH2_LPF                  2
  CH2_RC0                  2
  CH2_RC1                  2
  CH2_RE                   4
  CH2_SE                   4
  CH2_VBIAS                2
  CH2_VZERO                2
  CH3_CAPPOT               2
  CH3_CE                   4
  CH3_LPF                  2
  CH3_RC0                  2
  CH3_RC1                  2
  CH3_RE                   4
  CH3_SE                   4
  CH3_VBIAS                2
  CH3_VZERO                2
  CH4_CAPPOT               2
  CH4_CE                   4
  CH4_LPF                  2
  CH4_RC0                  2
  CH4_RC1                  2
  CH4_RE                   4
  CH4_SE                   4
  CH4_VBIAS                2
  CH4_VZERO                2
  SCL                      7
  SDA                      7
  U1_ADCVBIAS              2
  U1_ADDR                  2
  U1_AVDD_REG              2
  U1_BM                    2
  U1_DVDD_REG              2
  U1_DVDD_REG_AD           2
  U1_RCAL0                 2
  U1_RCAL1                 2
  U1_RX                    2
  U1_SWCLK                 2
  U1_SWDIO                 2
  U1_TX                    2
  U1_VDCDC_CAP1N           2
  U1_VDCDC_CAP1P           2
  U1_VDCDC_CAP2N           2
  U1_VDCDC_CAP2P           2
  U1_VDCDC_CAPOUT          2
  U1_VREF182               2
  U1_VREF25                2
  U2_ADCVBIAS              2
  U2_ADDR                  2
  U2_AVDD_REG              2
  U2_BM                    2
  U2_DVDD_REG              2
  U2_DVDD_REG_AD           2
  U2_RCAL0                 2
  U2_RCAL1                 2
  U2_RX                    2
  U2_SWCLK                 2
  U2_SWDIO                 2
  U2_TX                    2
  U2_VDCDC_CAP1N           2
  U2_VDCDC_CAP1P           2
  U2_VDCDC_CAP2N           2
  U2_VDCDC_CAP2P           2
  U2_VDCDC_CAPOUT          2
  U2_VREF182               2
  U2_VREF25                2
  ~{ALERT}                 4
  ~{RESET}                 6

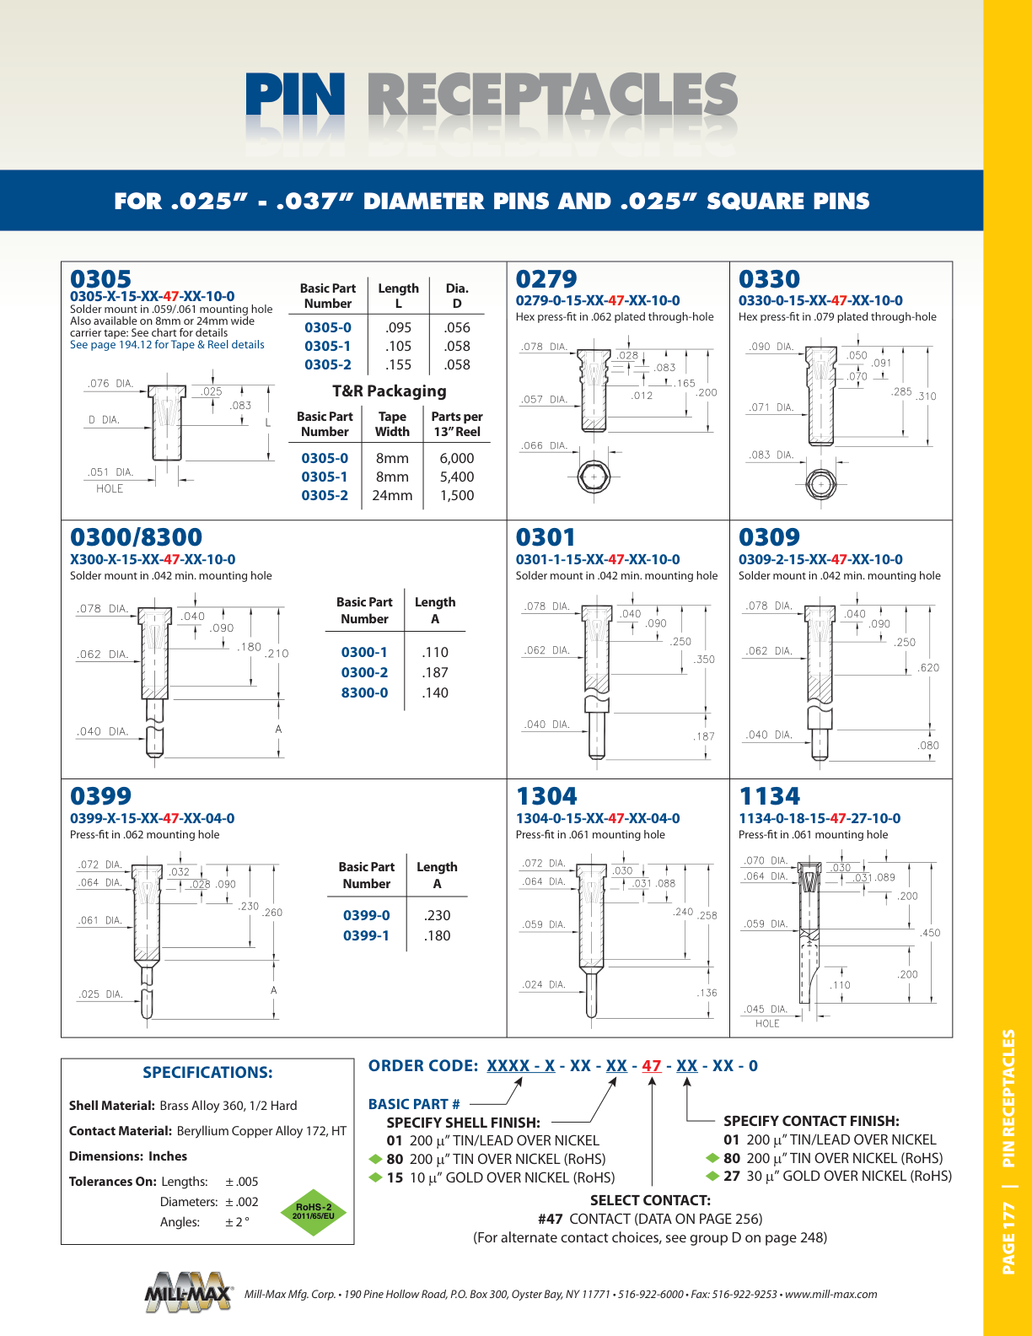
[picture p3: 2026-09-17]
verification/millmax-29.png

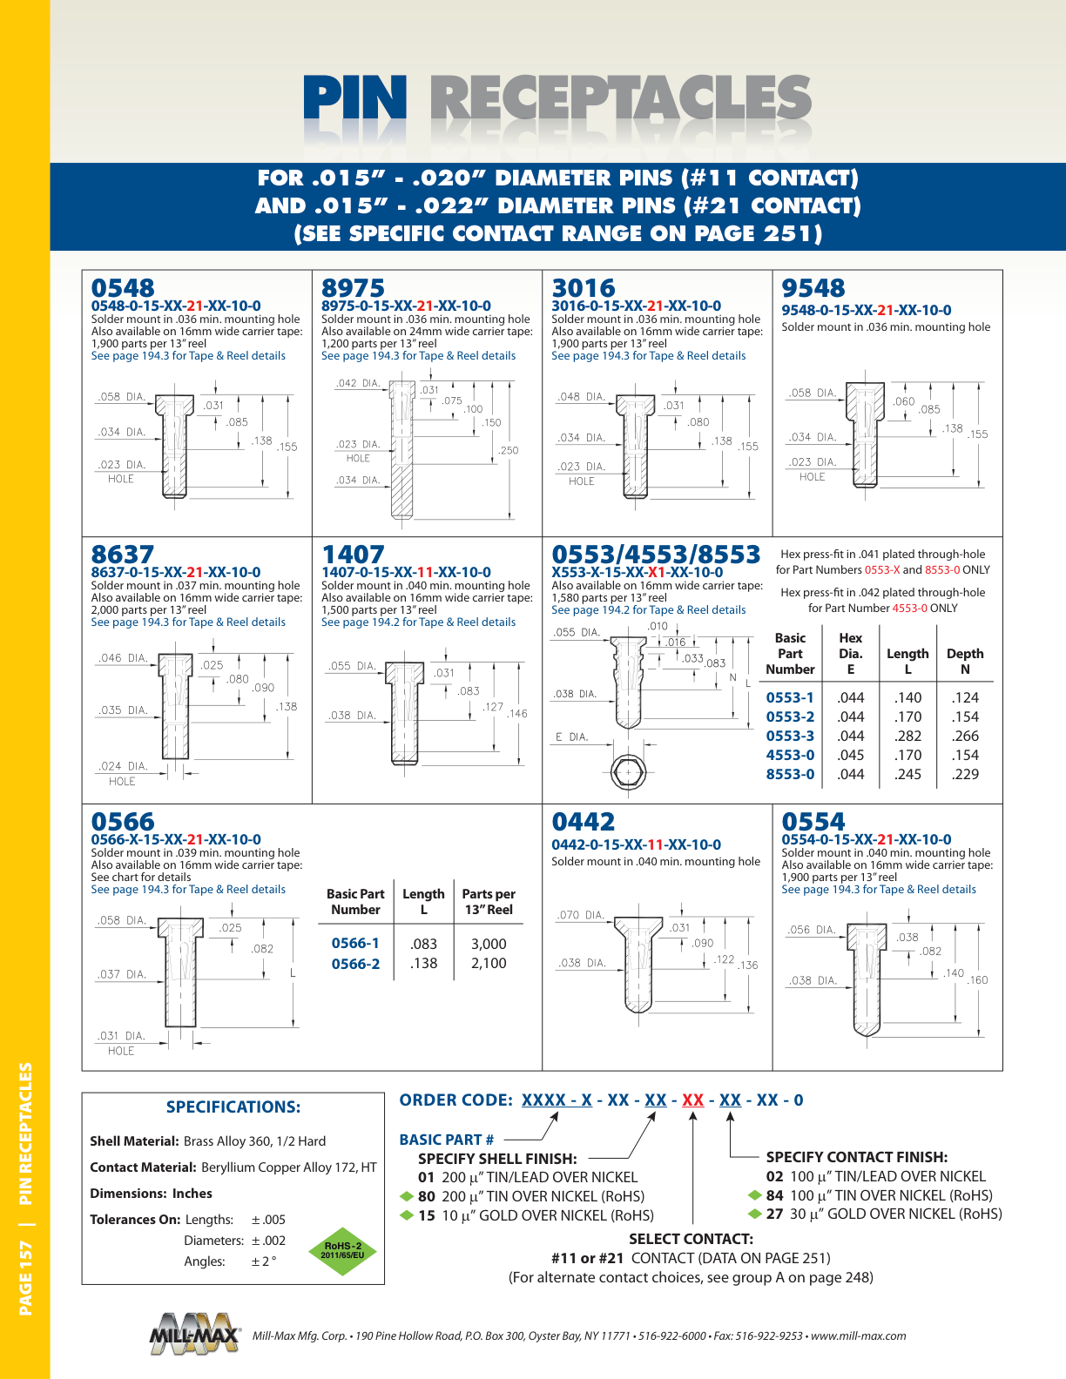
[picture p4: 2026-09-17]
verification/socket-choice.png

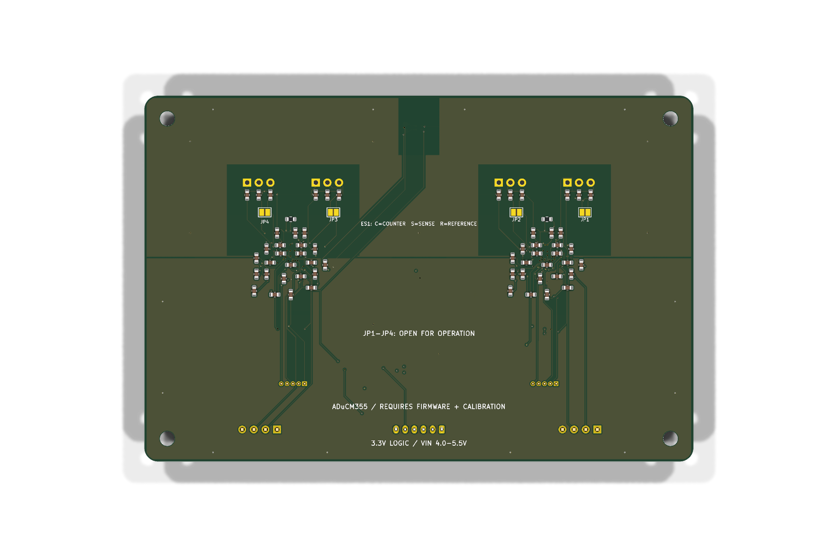
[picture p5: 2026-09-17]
verification/bottom-review.png

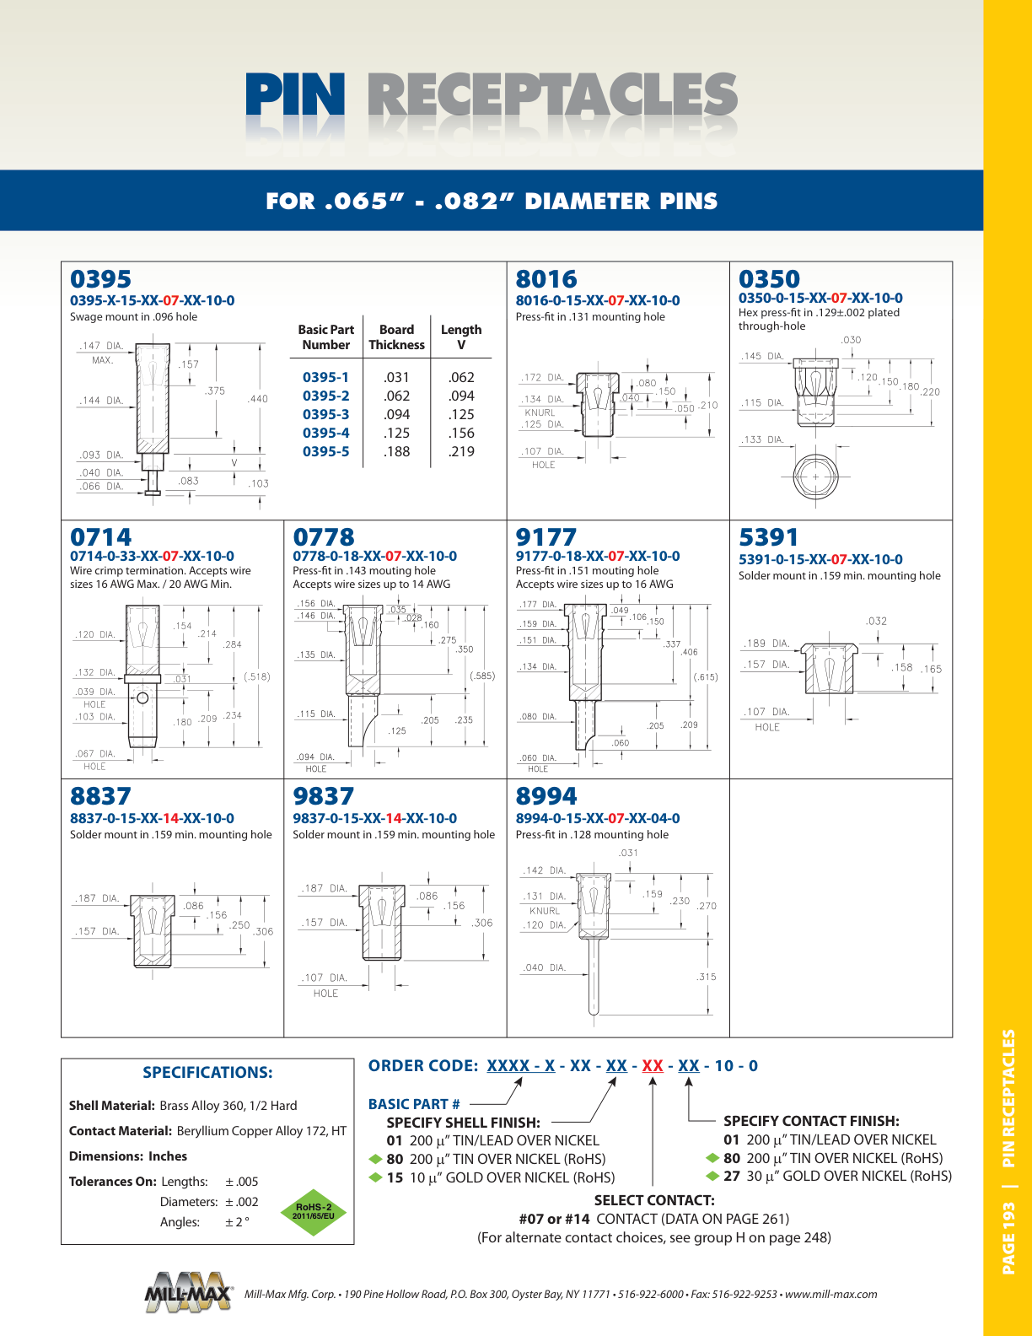
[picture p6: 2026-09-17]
verification/millmax-49.png

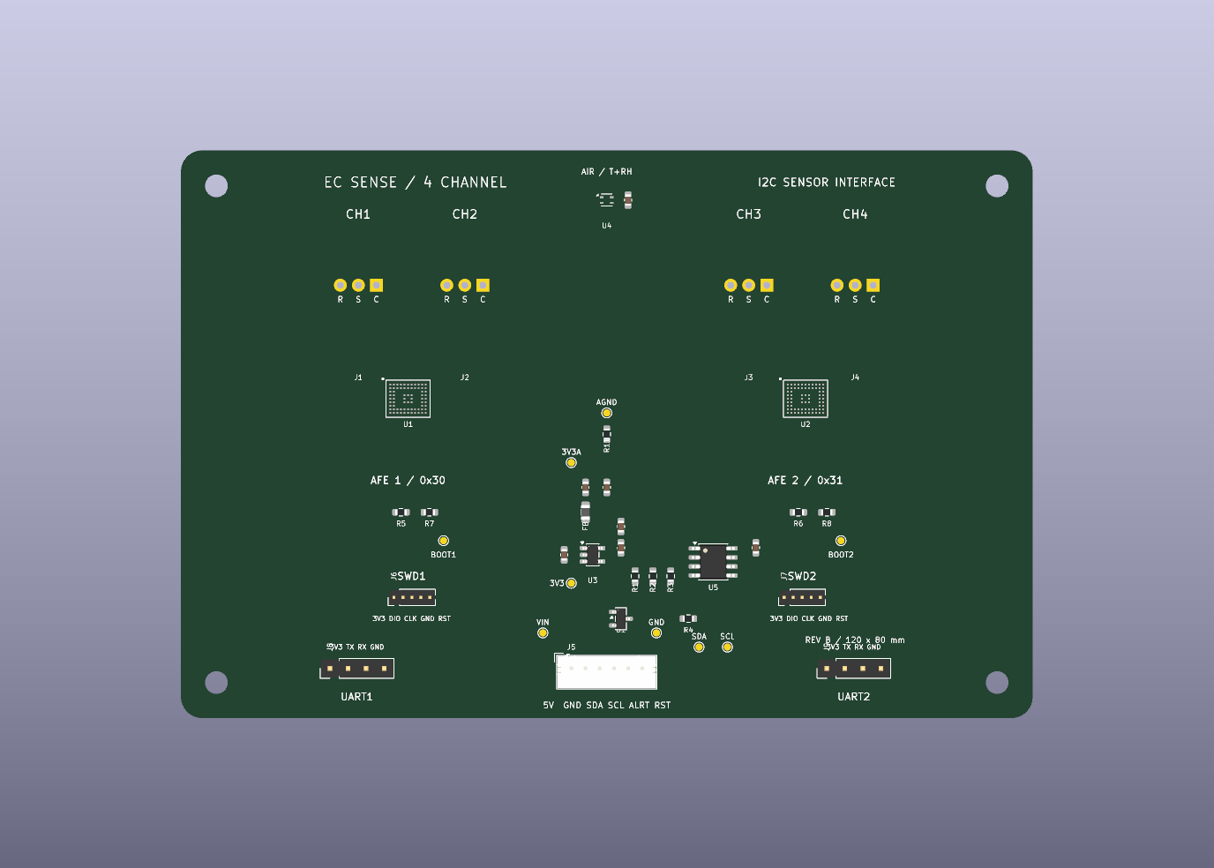
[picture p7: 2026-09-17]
verification/placement-top.png

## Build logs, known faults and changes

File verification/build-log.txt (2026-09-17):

./src/common/stdpbase.cpp(59): assert ""traits"" failed in Get(): create wxApp before calling this
Footprints 109 nets 132 outline 120.05 80.05
DSN export True

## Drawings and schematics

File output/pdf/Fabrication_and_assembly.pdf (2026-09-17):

# EC Sense - four-channel I2C PCB

### Revision B | 120 x 80 mm | Fabrication and assembly | 16 September 2026

## Fabrication specification

Board | 120.00 x 80.00 mm, R3 corners
Construction | 4 copper layers, 1.6 mm FR-4, ENIG
Track / space | 0.075 / 0.075 mm minimum
Fine vias | 0.20 mm finished drill / 0.40 mm pad
Stitching vias | 0.30 mm finished drill / 0.60 mm pad
Mounting | 4 x 3.2 mm NPTH; 110 x 70 mm pattern
Assembly | Components on both sides; tented vias

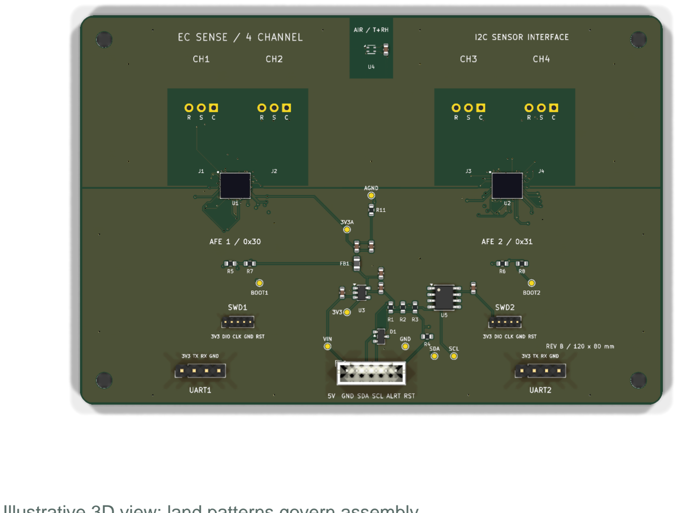
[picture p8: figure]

Illustrative 3D view; land patterns govern assembly.
Assembly: Fit all capacitors and R11. Leave JP1-JP4 open. Each sensor socket uses three Mill-Max 0548-0-15-15-21-27-10-0 receptacles. Insert gas sensors after soldering and cleaning.

Checks: Zero DRC violations, unconnected items, schematic mismatches and ERC violations. This is an untested hardware prototype: firmware, gas-specific setup, zero/span calibration and bench validation remain required.

Outputs: Use the Gerbers and separate PTH/NPTH drills for fabrication. Absolute KiCad origin is shared across outputs. Bottom assembly is viewed from below; do not mirror Gerbers. See PCB_README.md for power, connectors and bring-up.

ECSense_4CH_I2C - revision B | Hardware prototype / manufacturing notes

## Mechanical - dimensions in millimeters

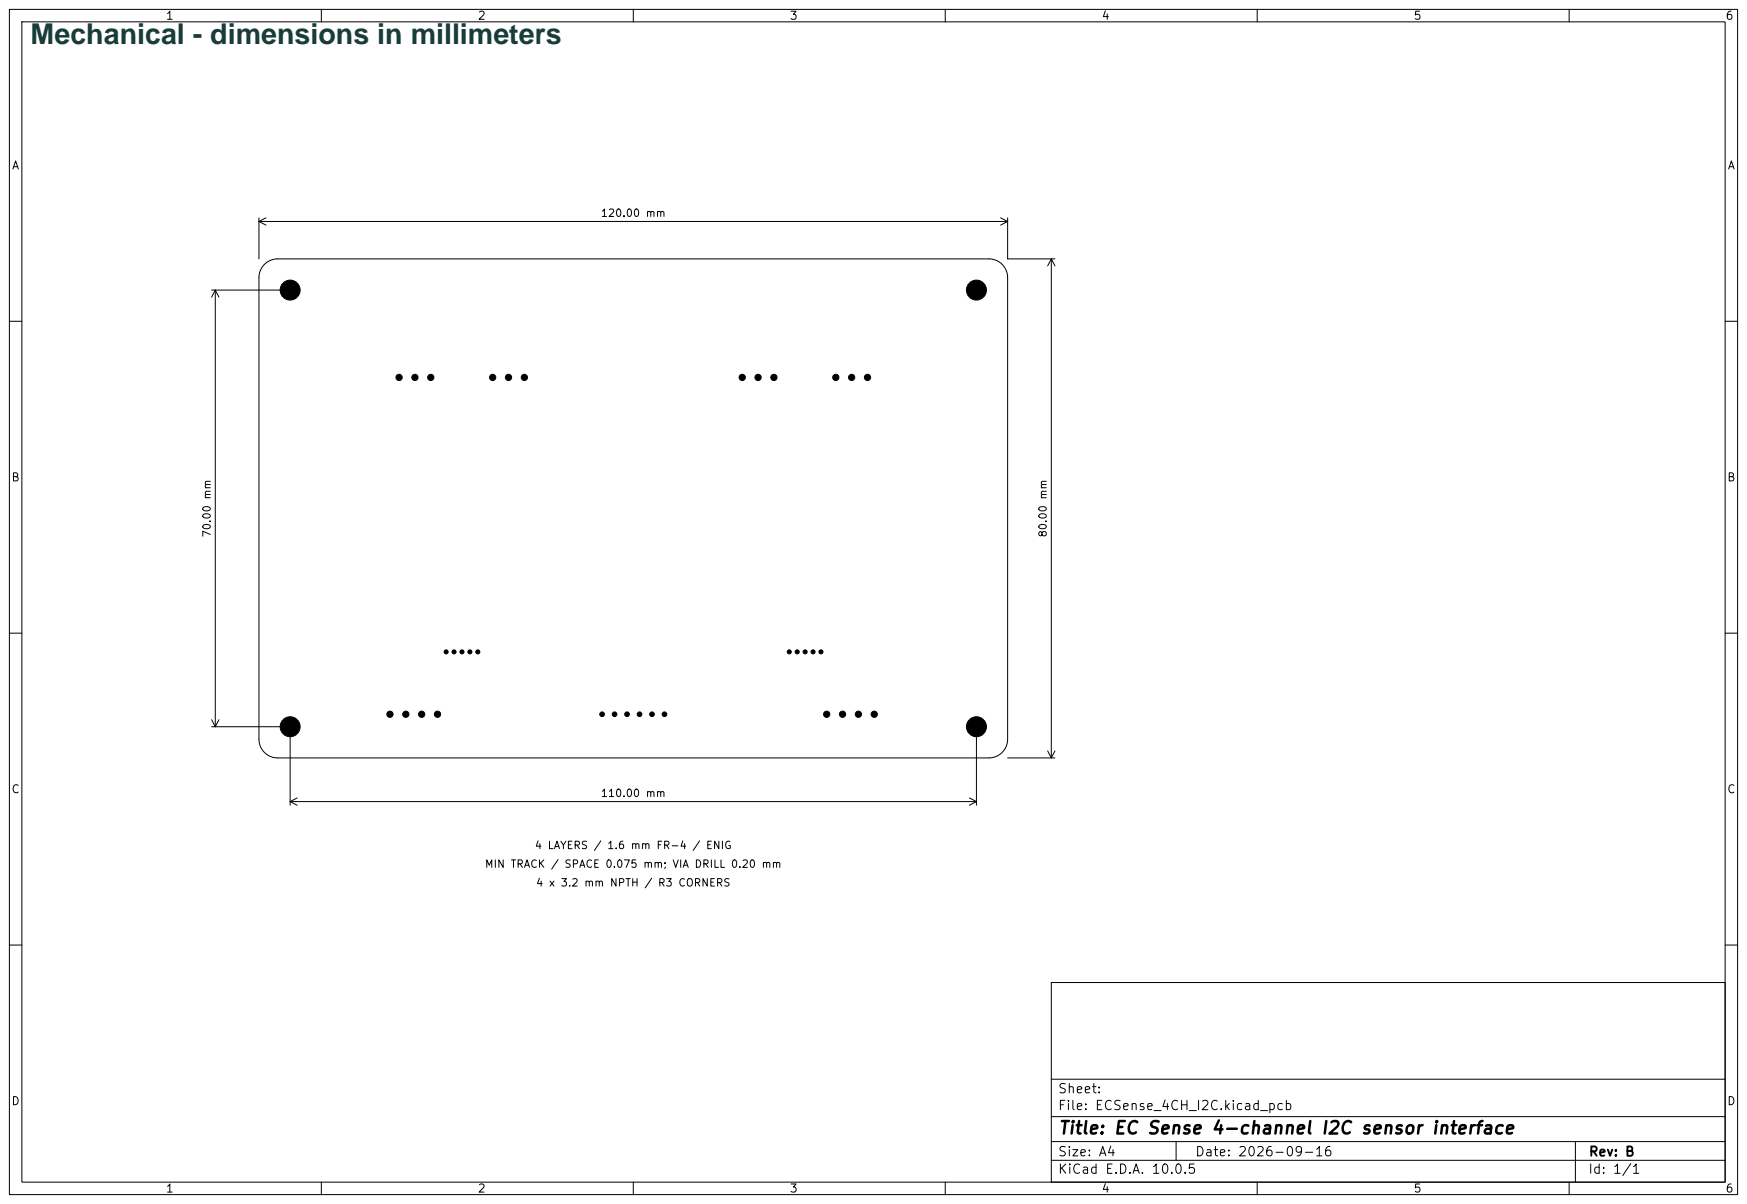
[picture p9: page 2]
D Date: 2026-09-16; Size: A4; Rev: B

4 LAYERS / 1.6 mm FR-4 / ENIG MIN TRACK / SPACE 0.075 mm; VIA DRILL 0.20 mm

4 x 3.2 mm NPTH / R3 CORNERS

Sheet:
File: ECSense_4CH_I2C.kicad_pcb
Title: EC Sense 4-channel I2C sensor interface
KiCad E.D.A. 10.0.5

## Assembly - front

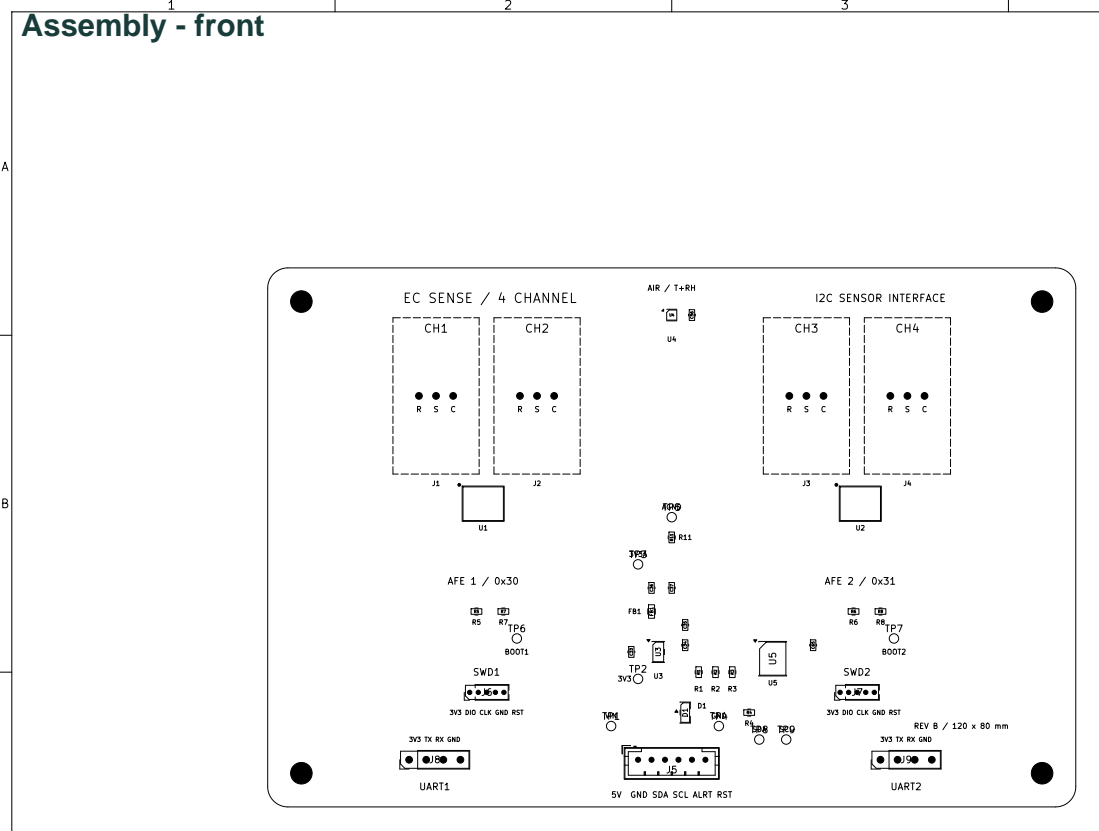
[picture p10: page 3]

5V GND SDA SCL ALRT RST UART1

File: ECSense_4CH_I2C.kicad_pcb
Title: EC Sense 4-channel I2C sensor interface

## Assembly - bottom, viewed from below

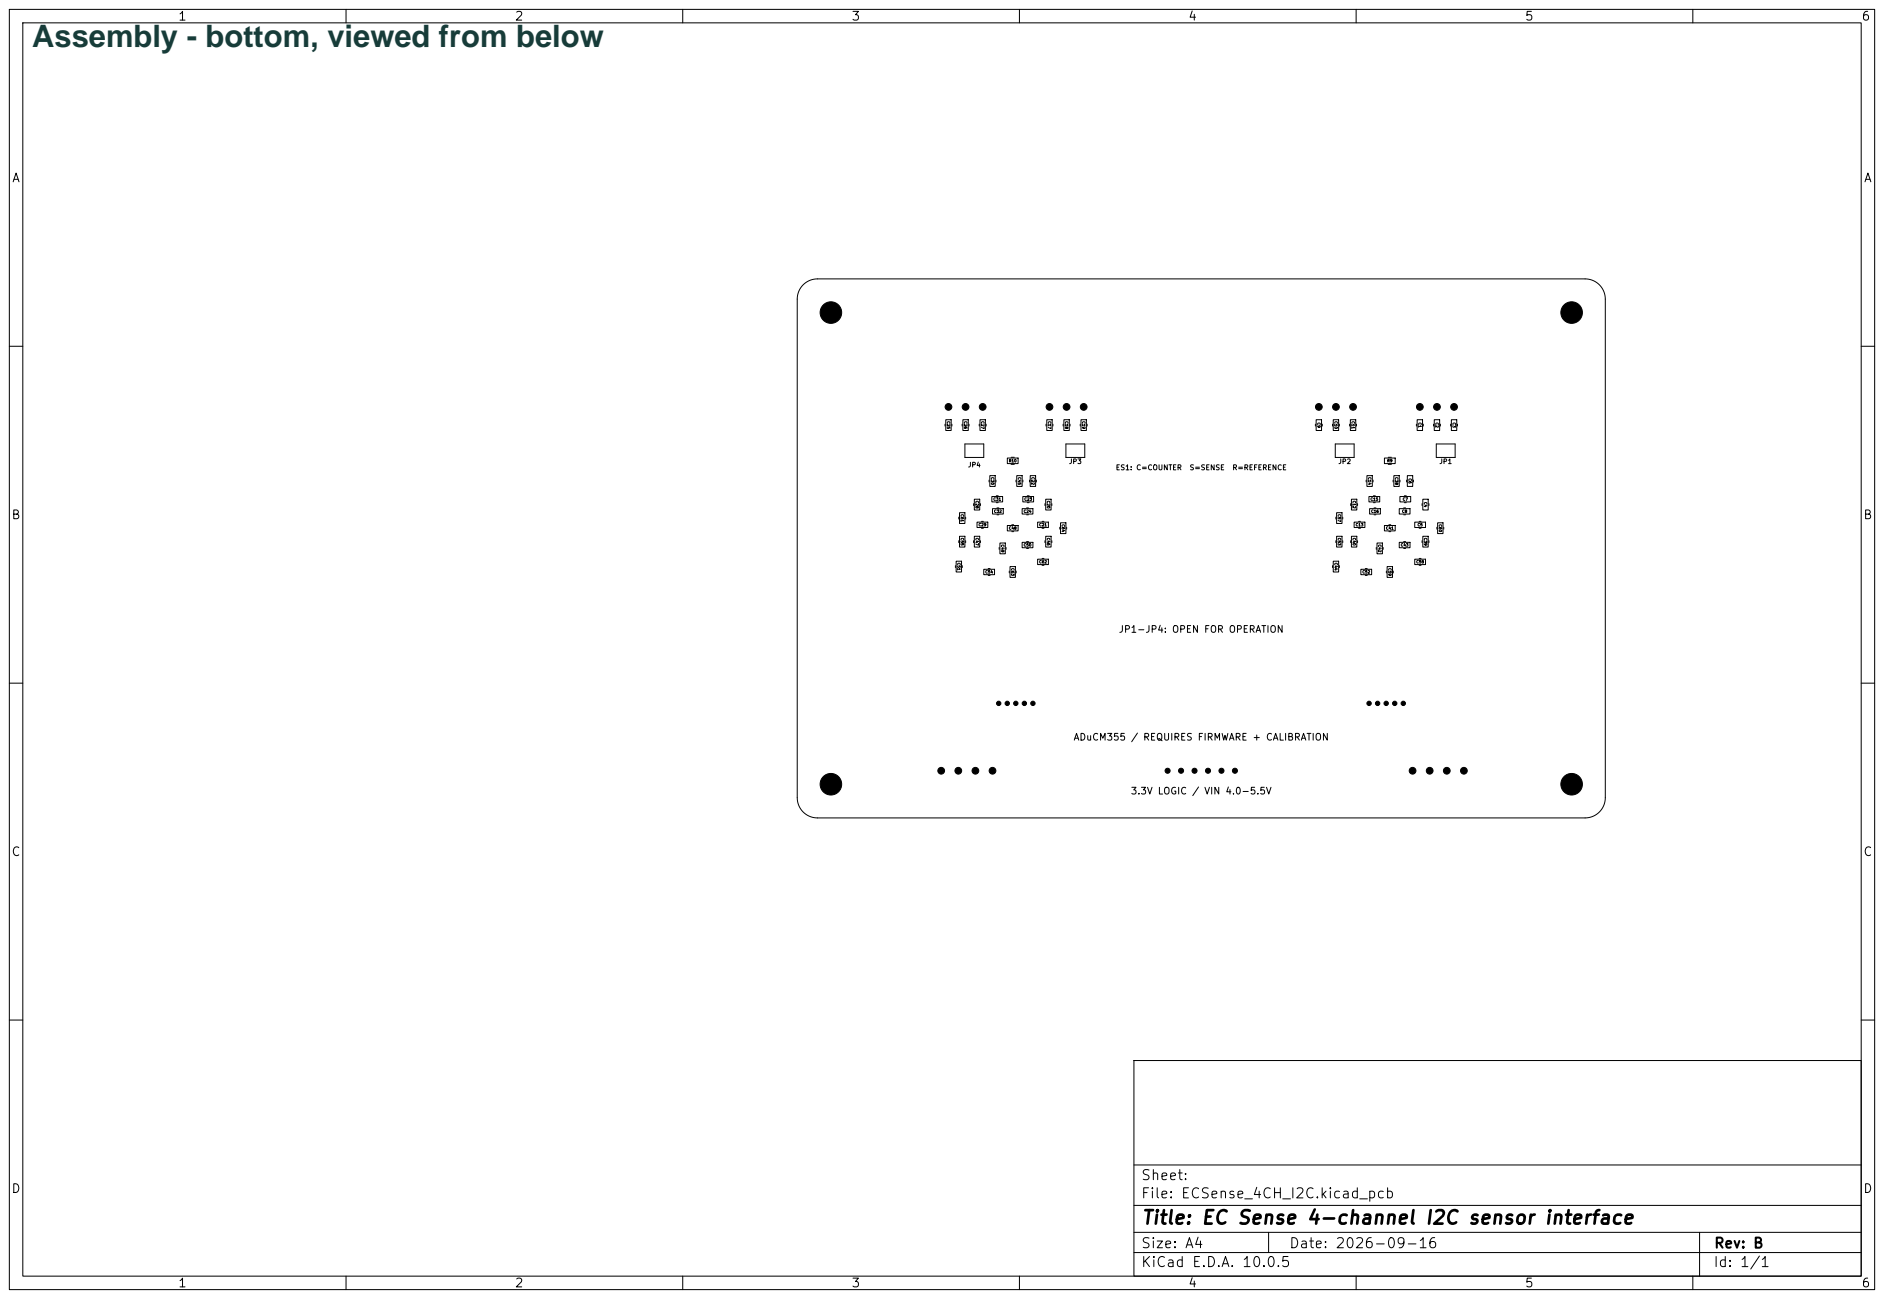
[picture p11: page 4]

File: ECSense_4CH_I2C.kicad_pcb
Title: EC Sense 4-channel I2C sensor interface

## Plated drill map

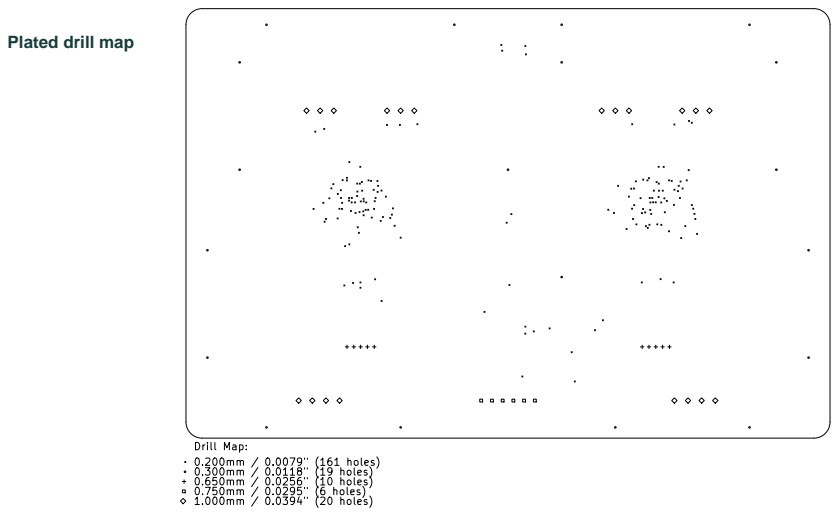
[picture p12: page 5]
Drill Map:; 0.200mm / 0.0079" (161 holes) 0.300mm

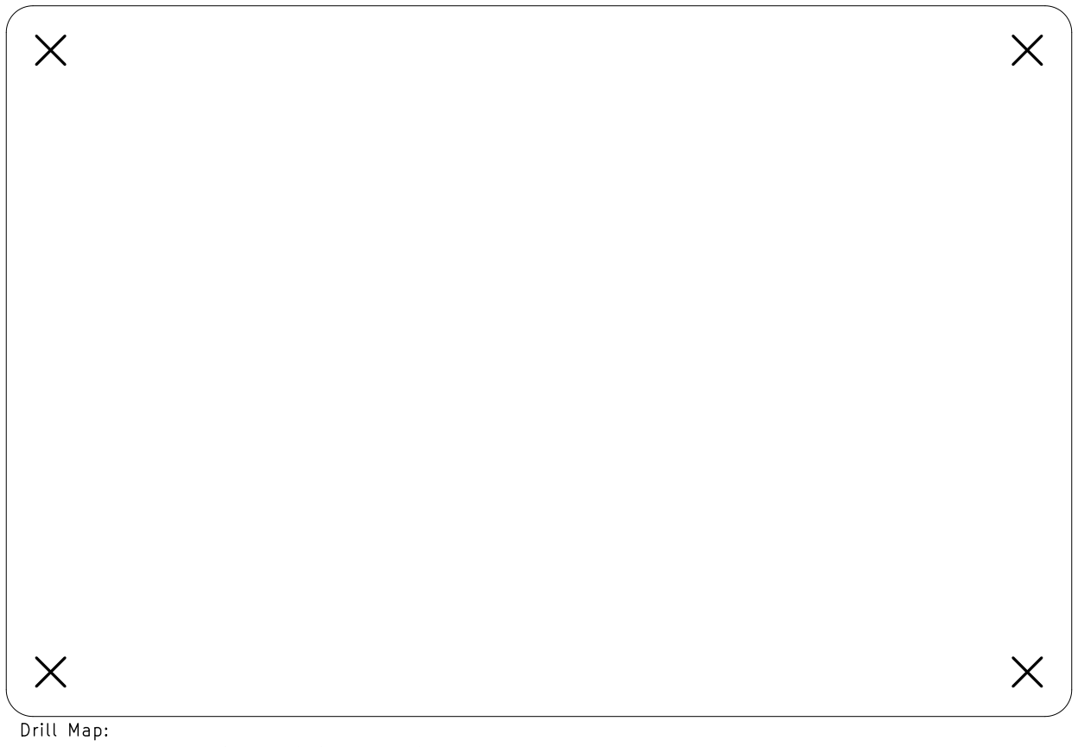
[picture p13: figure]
Drill Map:

3.200mm / 0.1260" (4 holes) (not plated)

## Nonplated drill map

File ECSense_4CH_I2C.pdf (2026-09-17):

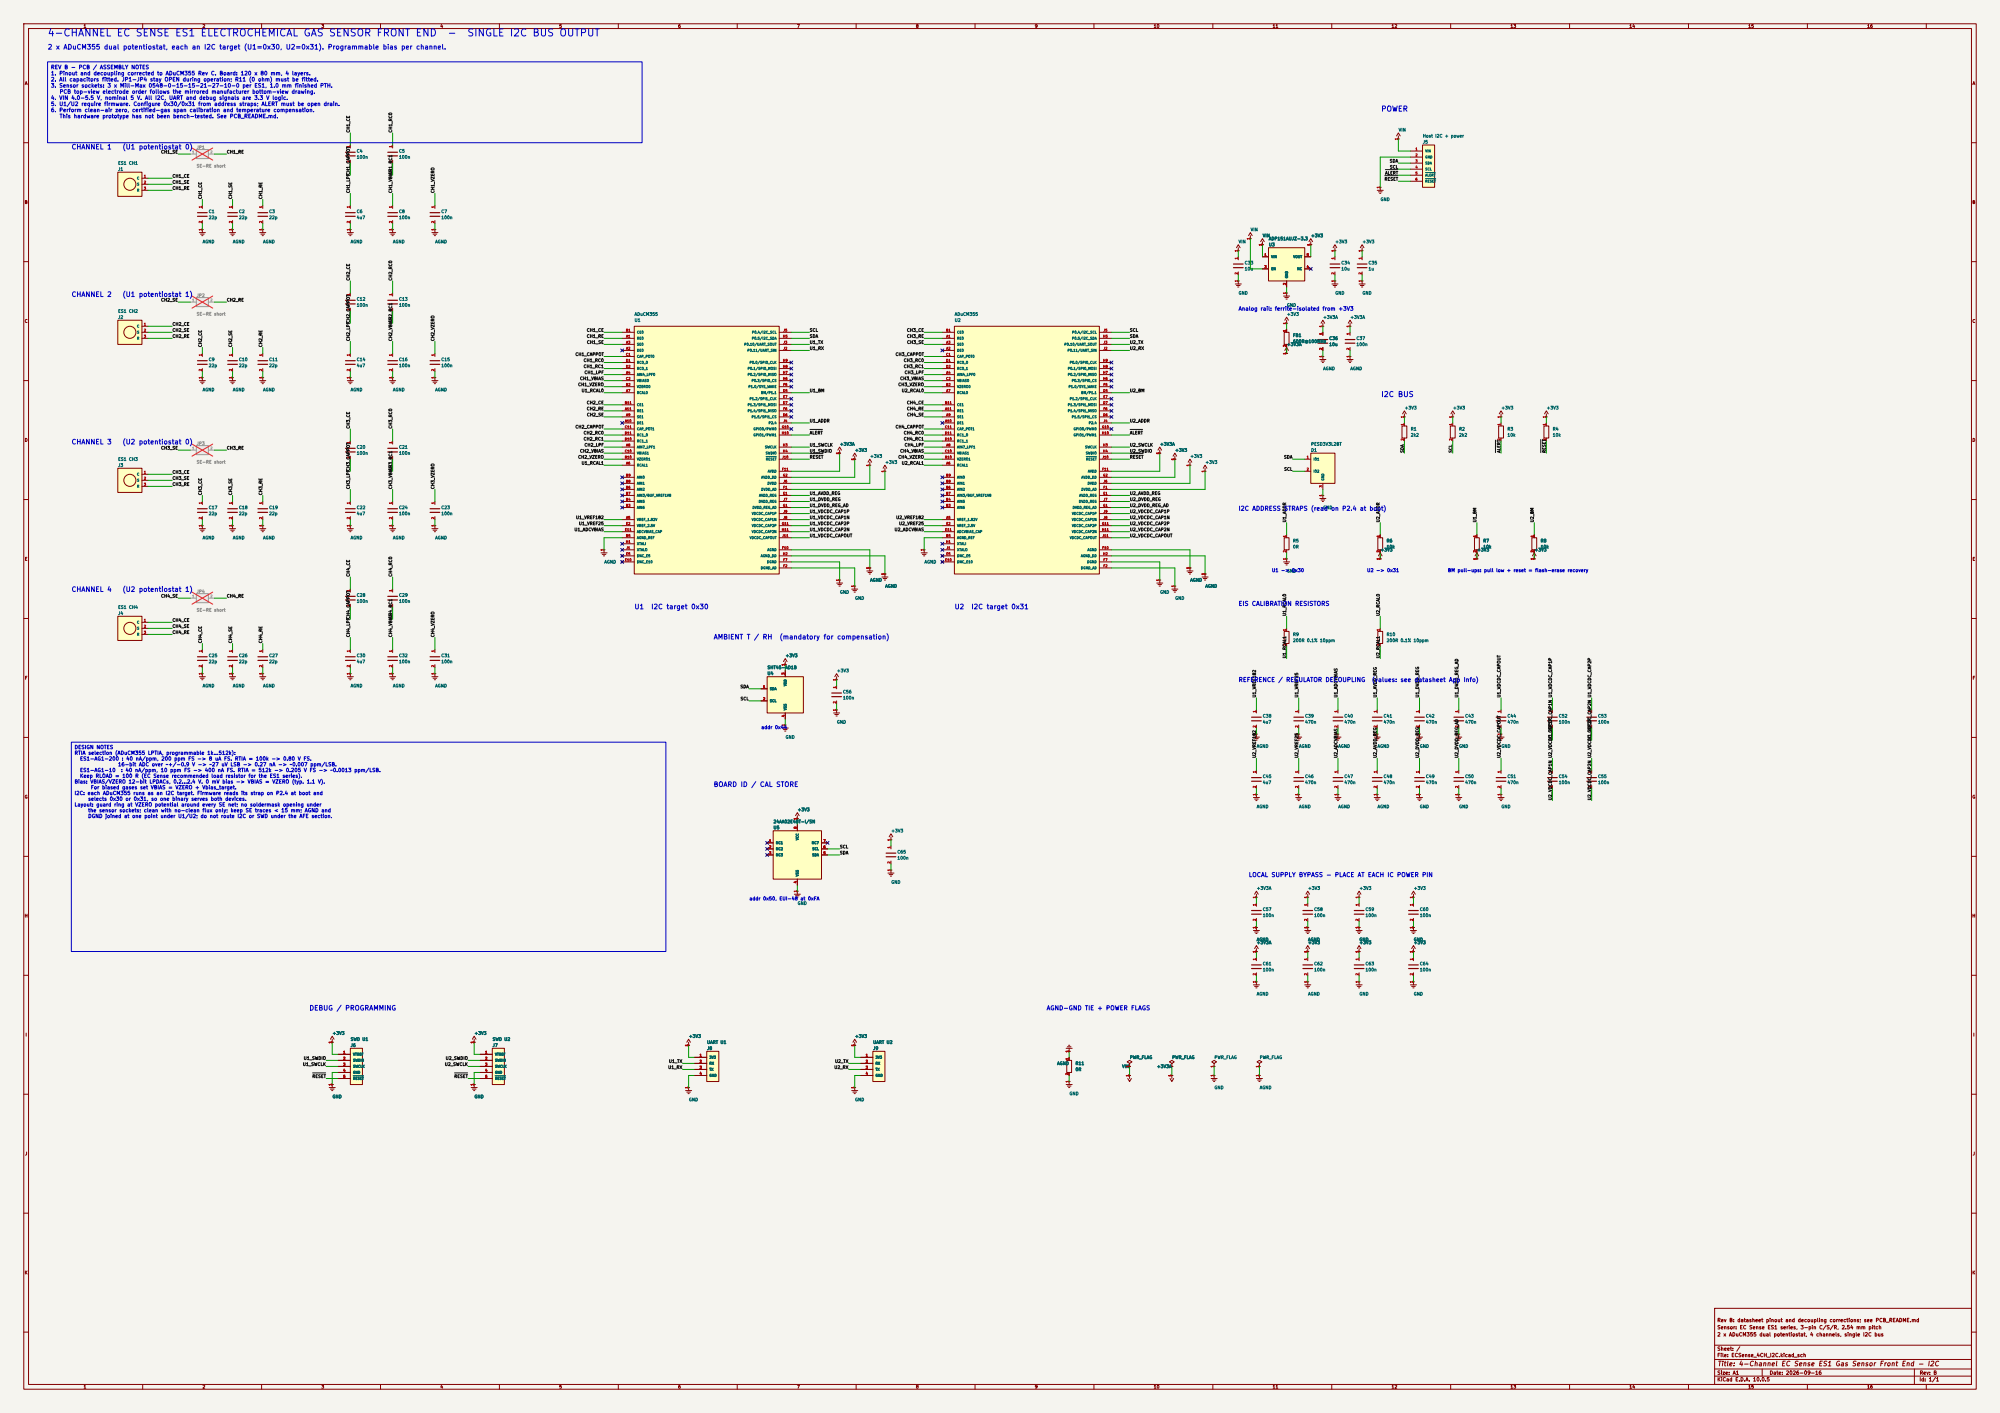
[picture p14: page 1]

4-CHANNEL EC SENSE ES1 ELECTROCHEMICAL GAS SENSOR FRONT END - SINGLE I2C BUS OUTPUT

2 x ADuCM355 dual potentiostat, each an I2C target (U1=0x30, U2=0x31). Programmable bias per channel.

REV B - PCB / ASSEMBLY NOTES
1. Pinout and decoupling corrected to ADuCM355 Rev C. Board: 120 x 80 mm, 4 layers.
2. All capacitors fitted. JP1-JP4 stay OPEN during operation; R11 (0 ohm) must be fitted.
3. Sensor sockets: 3 x Mill-Max 0548-0-15-15-21-27-10-0 per ES1, 1.0 mm finished PTH.
PCB top-view electrode order follows the mirrored manufacturer bottom-view drawing.
4. VIN 4.0-5.5 V, nominal 5 V. All I2C, UART and debug signals are 3.3 V logic.
5. U1/U2 require firmware. Configure 0x30/0x31 from address straps; ALERT must be open drain.
6. Perform clean-air zero, certified-gas span calibration and temperature compensation.
This hardware prototype has not been bench-tested. See PCB_README.md.

Analog rail: ferrite-isolated from +3V3

I2C ADDRESS STRAPS (read on P2.4 at boot)

REFERENCE / REGULATOR DECOUPLING (values: see datasheet App Info) U1 -> 0x30 EIS CALIBRATION RESISTORS

BM pull-ups: pull low + reset = flash-erase recovery

AMBIENT T / RH (mandatory for compensation)

DESIGN NOTES
RTIA selection (ADuCM355 LPTIA, programmable 1k...512k):
ES1-AG1-200 : 40 nA/ppm, 200 ppm FS -> 8 uA FS. RTIA = 100k -> 0.80 V FS.

ES1-AG1-10 : 40 nA/ppm, 10 ppm FS -> 400 nA FS. RTIA = 512k -> 0.205 V FS -> ~0.0013 ppm/LSB.
Keep RLOAD = 100 R (EC Sense recommended load resistor for the ES1 series).
Bias: VBIAS/VZERO 12-bit LPDACs, 0.2...2.4 V. 0 mV bias -> VBIAS = VZERO (typ. 1.1 V).
For biased gases set VBIAS = VZERO + Vbias_target.
I2C: each ADuCM355 runs as an I2C target. Firmware reads its strap on P2.4 at boot and
selects 0x30 or 0x31, so one binary serves both devices.
Layout: guard ring at VZERO potential around every SE net; no soldermask opening under
the sensor sockets; clean with no-clean flux only; keep SE traces < 15 mm; AGND and
DGND joined at one point under U1/U2; do not route I2C or SWD under the AFE section.

16-bit ADC over ~+/-0.9 V -> ~27 uV LSB -> 0.27 nA -> ~0.007 ppm/LSB.

BOARD ID / CAL STORE

LOCAL SUPPLY BYPASS - PLACE AT EACH IC POWER PIN

AGND-GND TIE + POWER FLAGS

Rev B: datasheet pinout and decoupling corrections; see PCB_README.md
Sensor: EC Sense ES1 series, 3-pin C/S/R, 2.54 mm pitch
2 x ADuCM355 dual potentiostat, 4 channels, single I2C bus

Sheet: /
File: ECSense_4CH_I2C.kicad_sch
Title: 4-Channel EC Sense ES1 Gas Sensor Front End - I2C

Size: A1 | Rev: B
KiCad E.D.A. 10.0.5 | Id: 1/1

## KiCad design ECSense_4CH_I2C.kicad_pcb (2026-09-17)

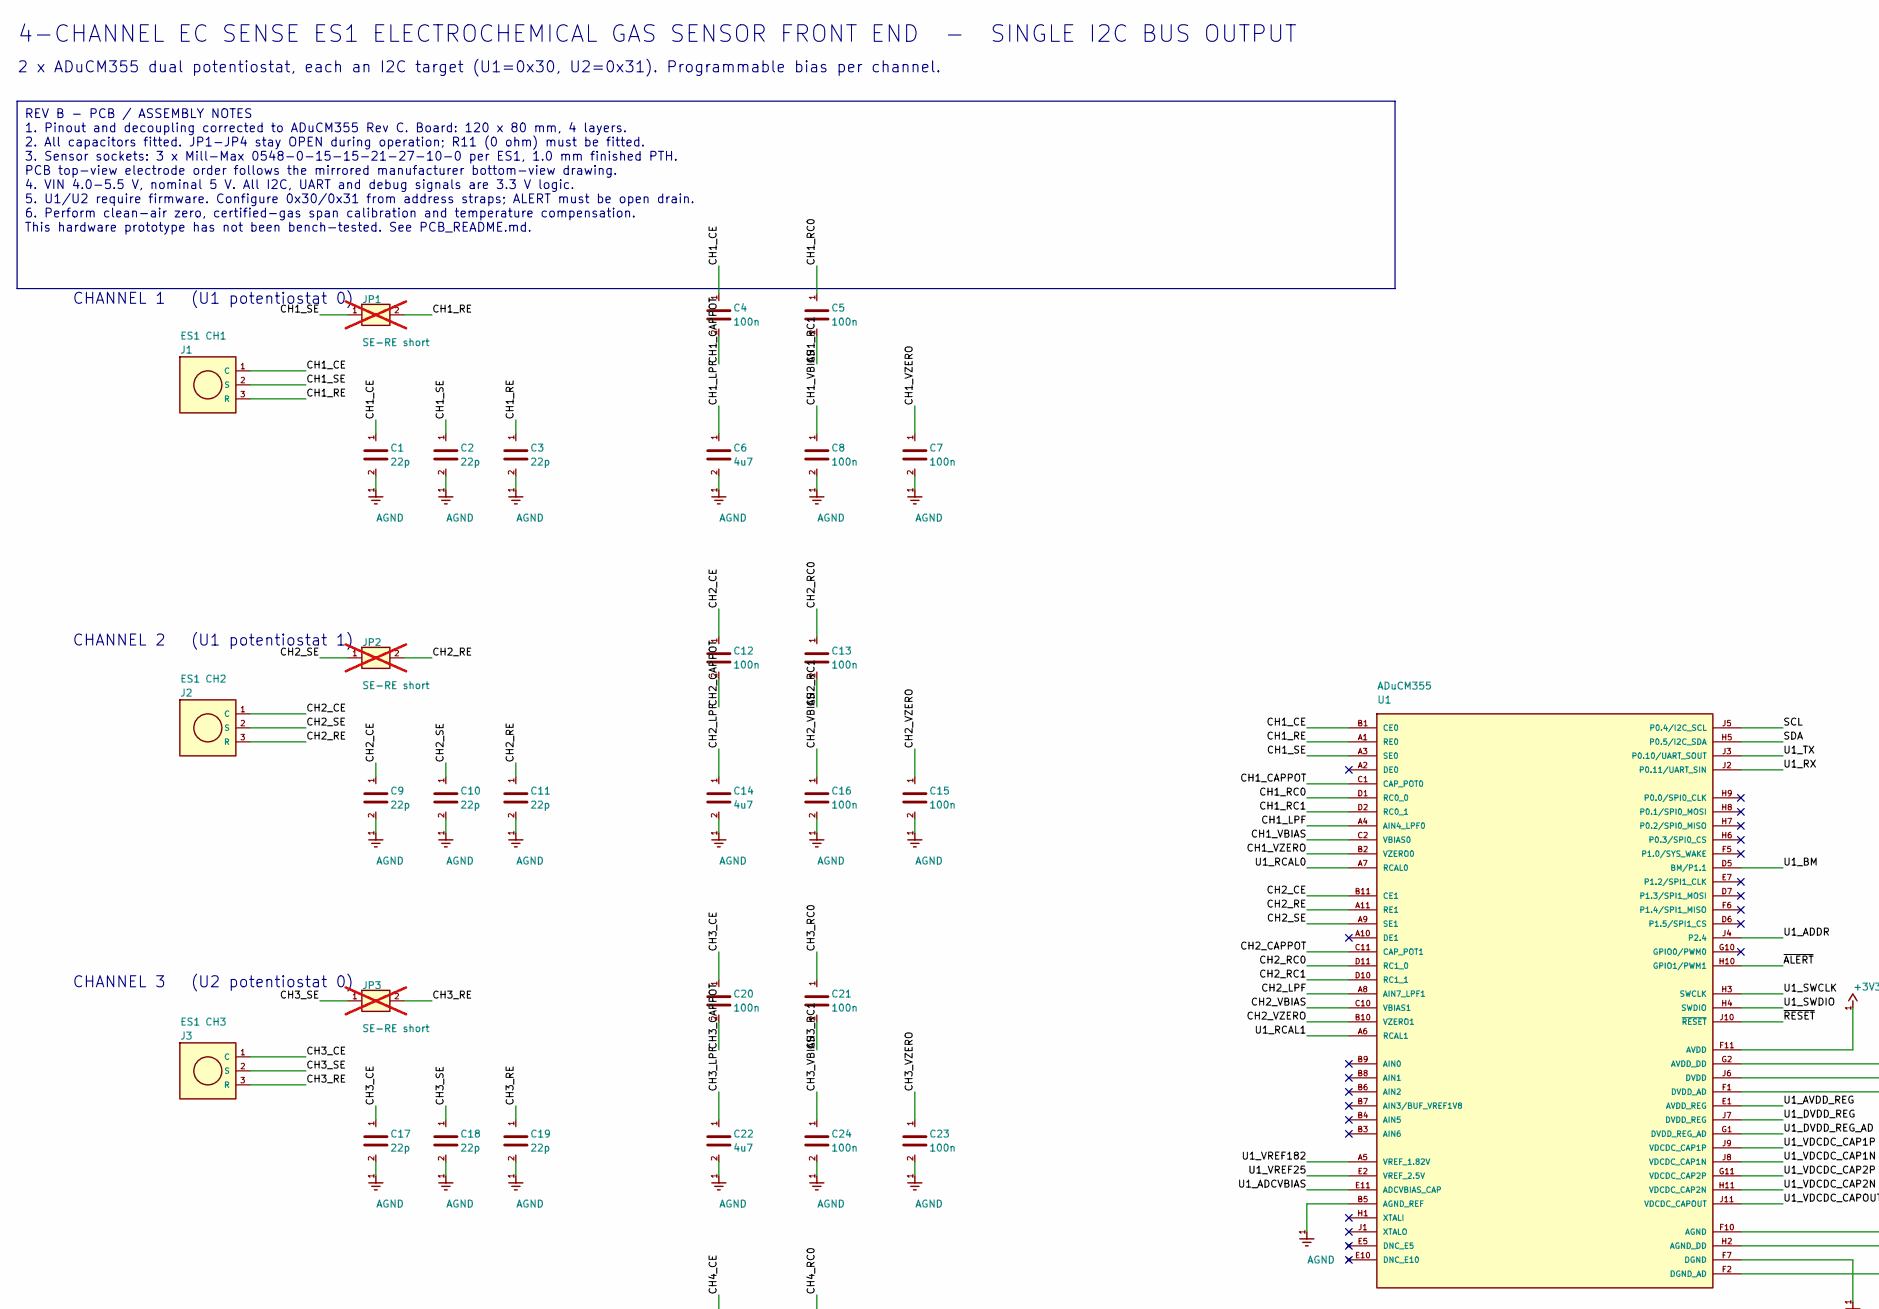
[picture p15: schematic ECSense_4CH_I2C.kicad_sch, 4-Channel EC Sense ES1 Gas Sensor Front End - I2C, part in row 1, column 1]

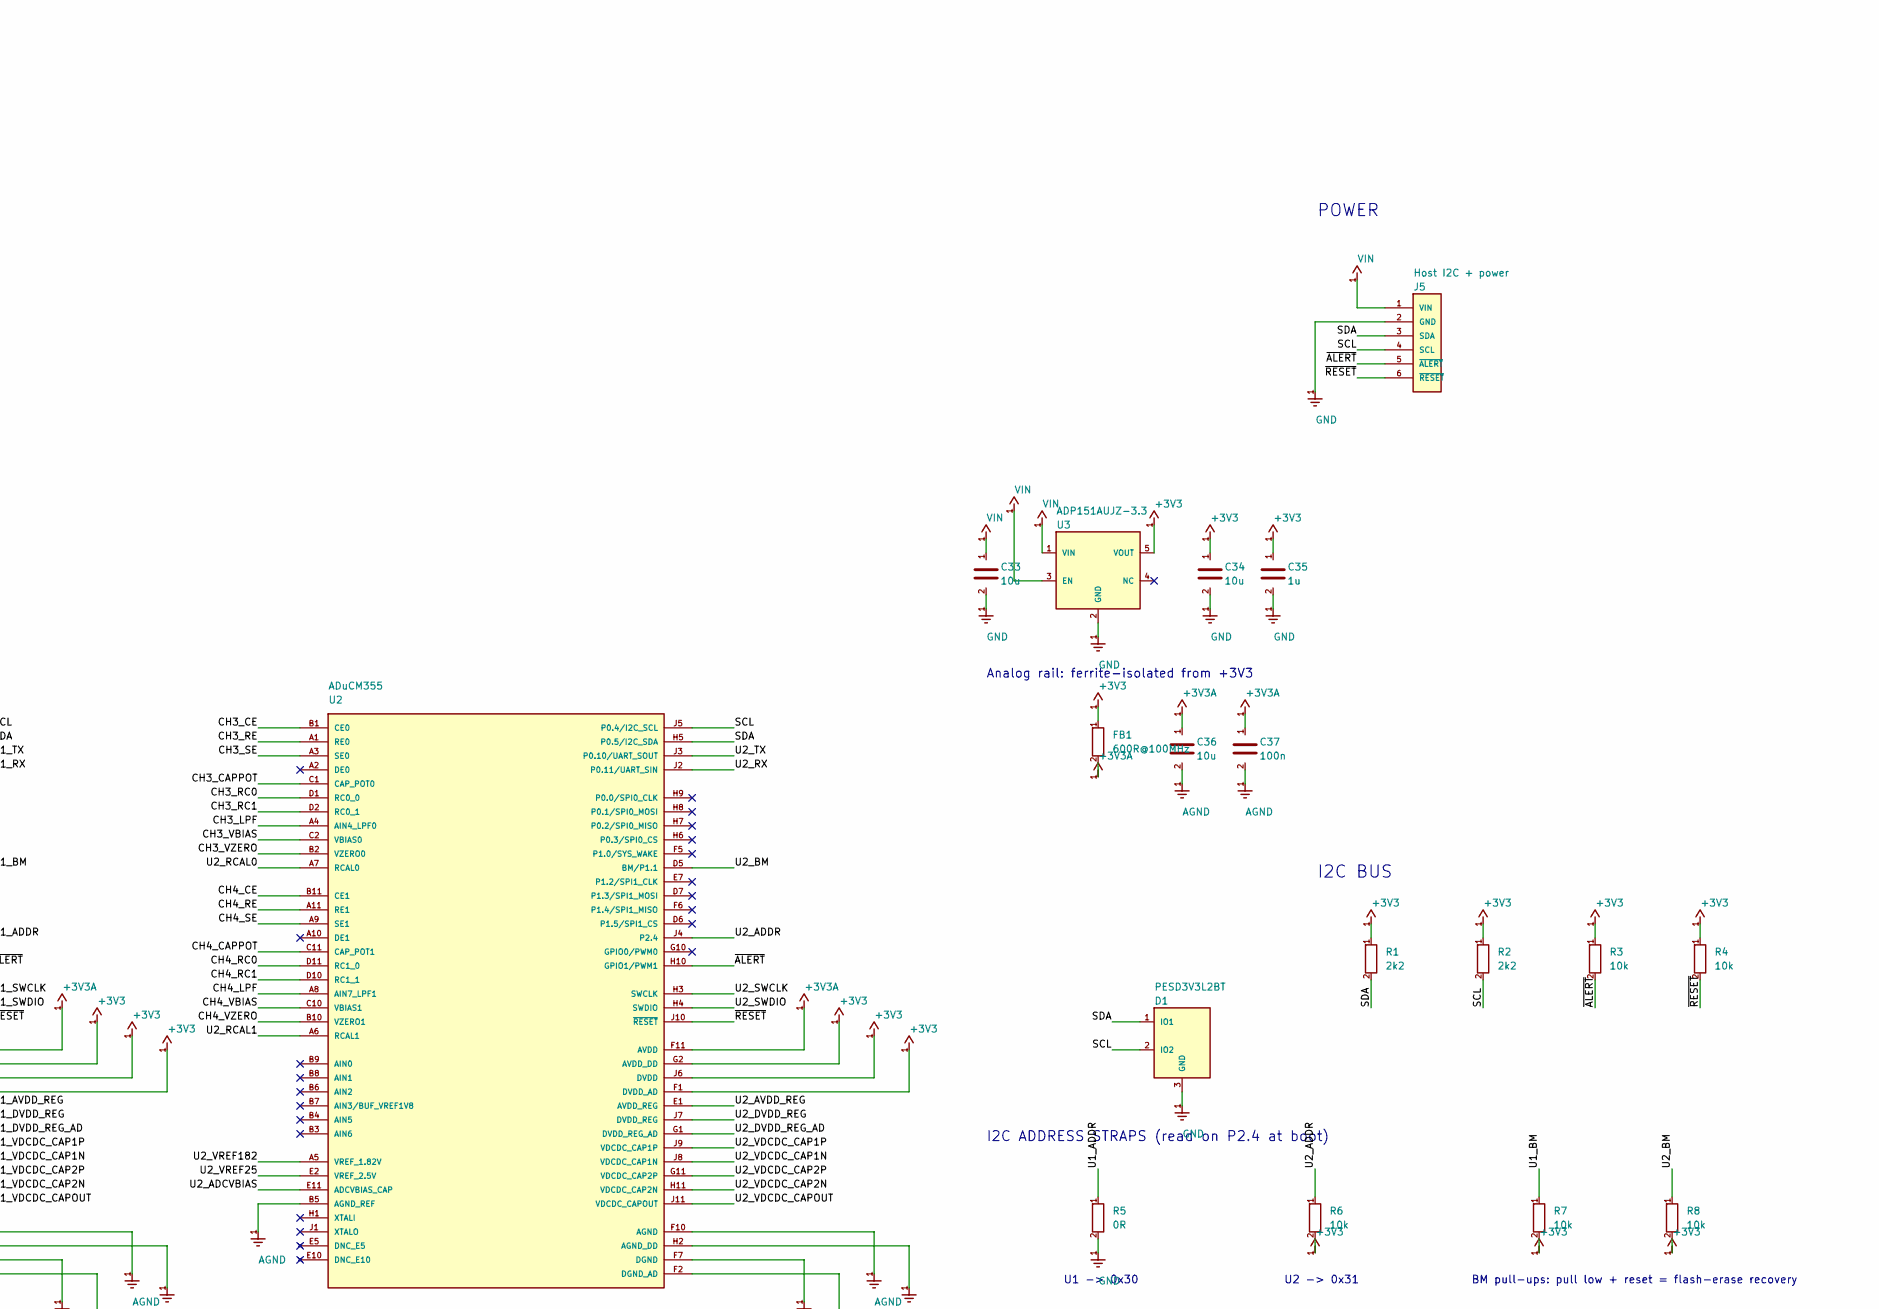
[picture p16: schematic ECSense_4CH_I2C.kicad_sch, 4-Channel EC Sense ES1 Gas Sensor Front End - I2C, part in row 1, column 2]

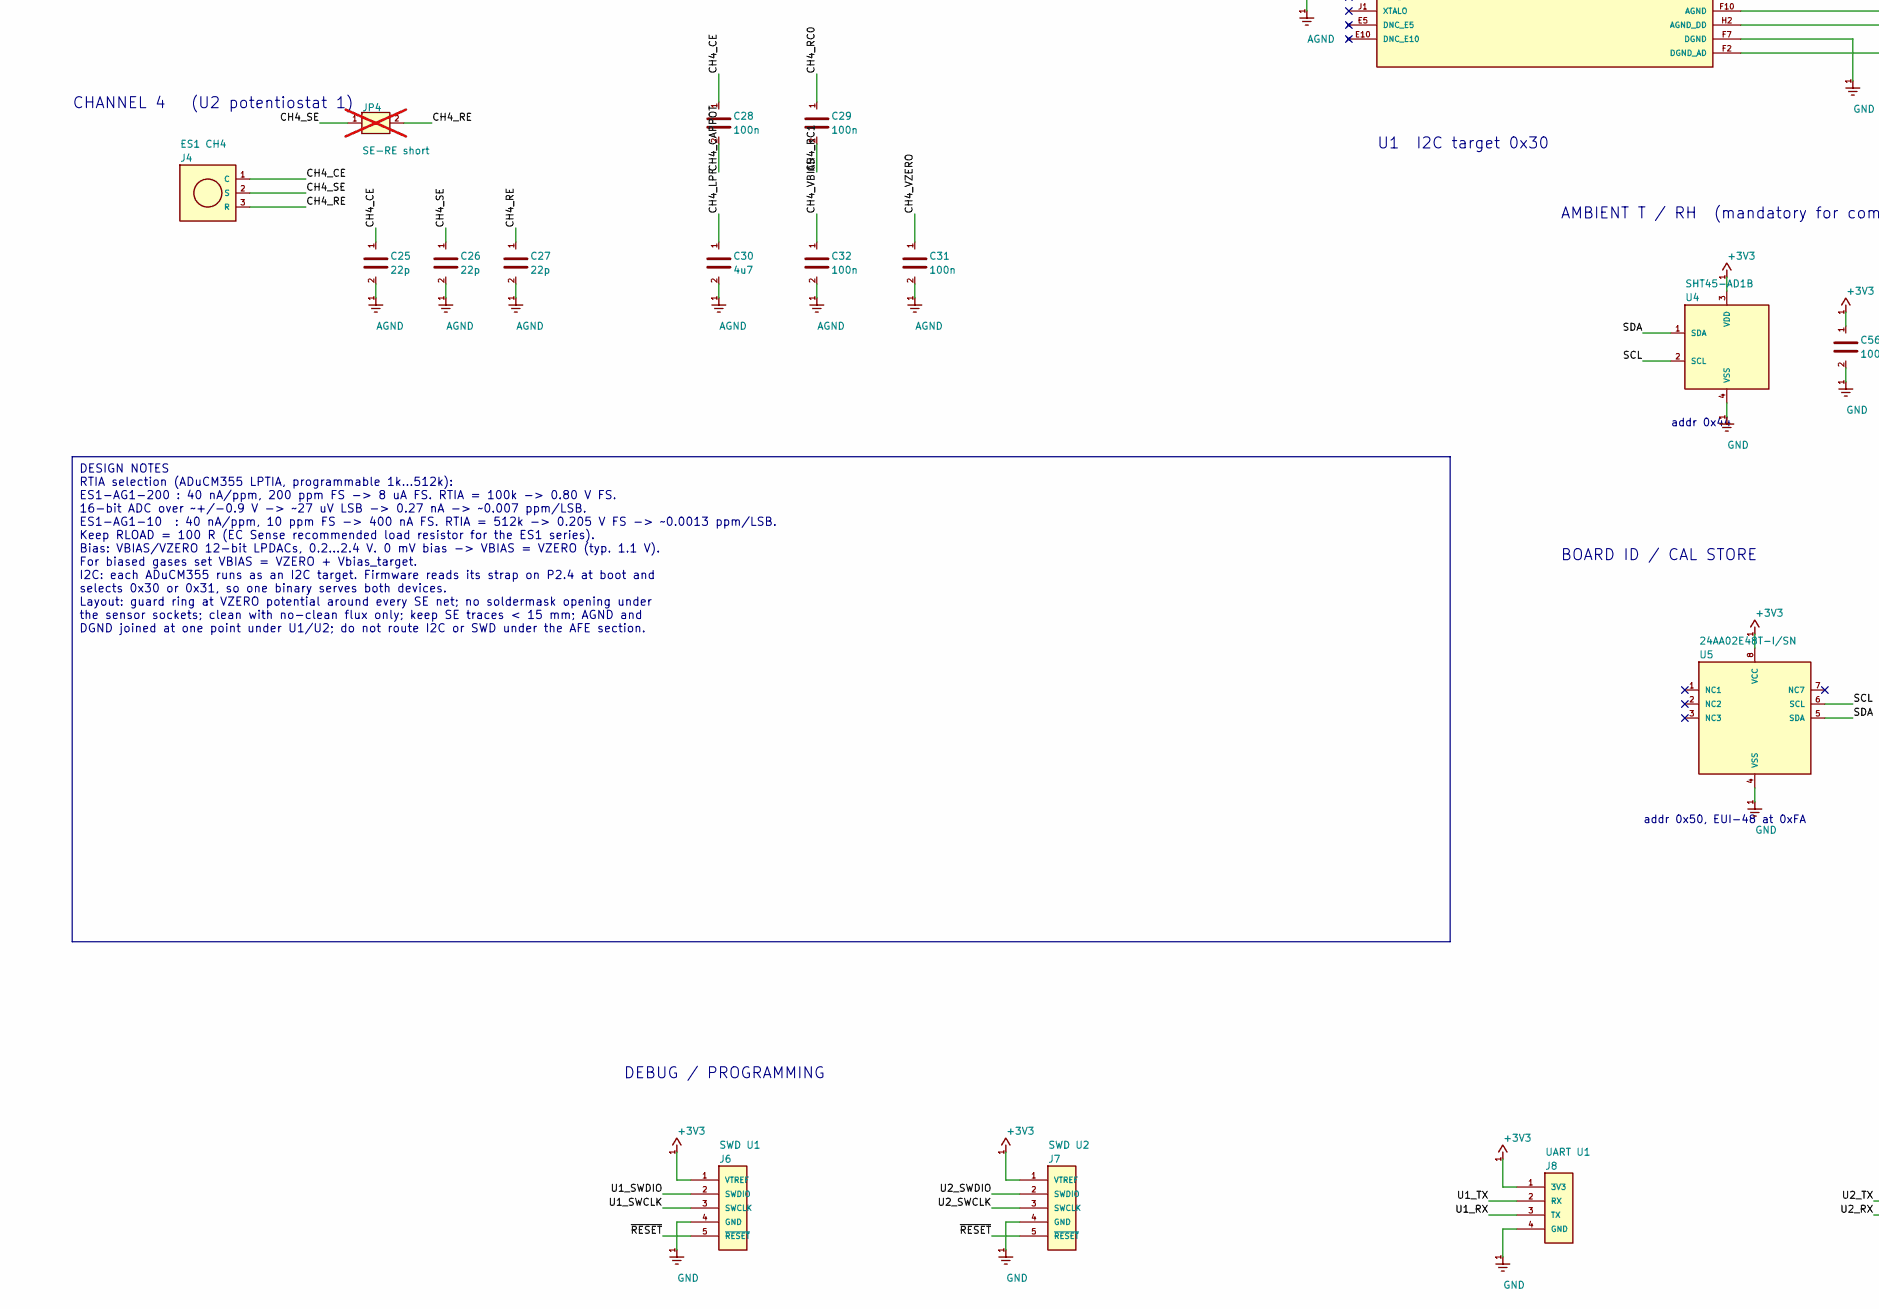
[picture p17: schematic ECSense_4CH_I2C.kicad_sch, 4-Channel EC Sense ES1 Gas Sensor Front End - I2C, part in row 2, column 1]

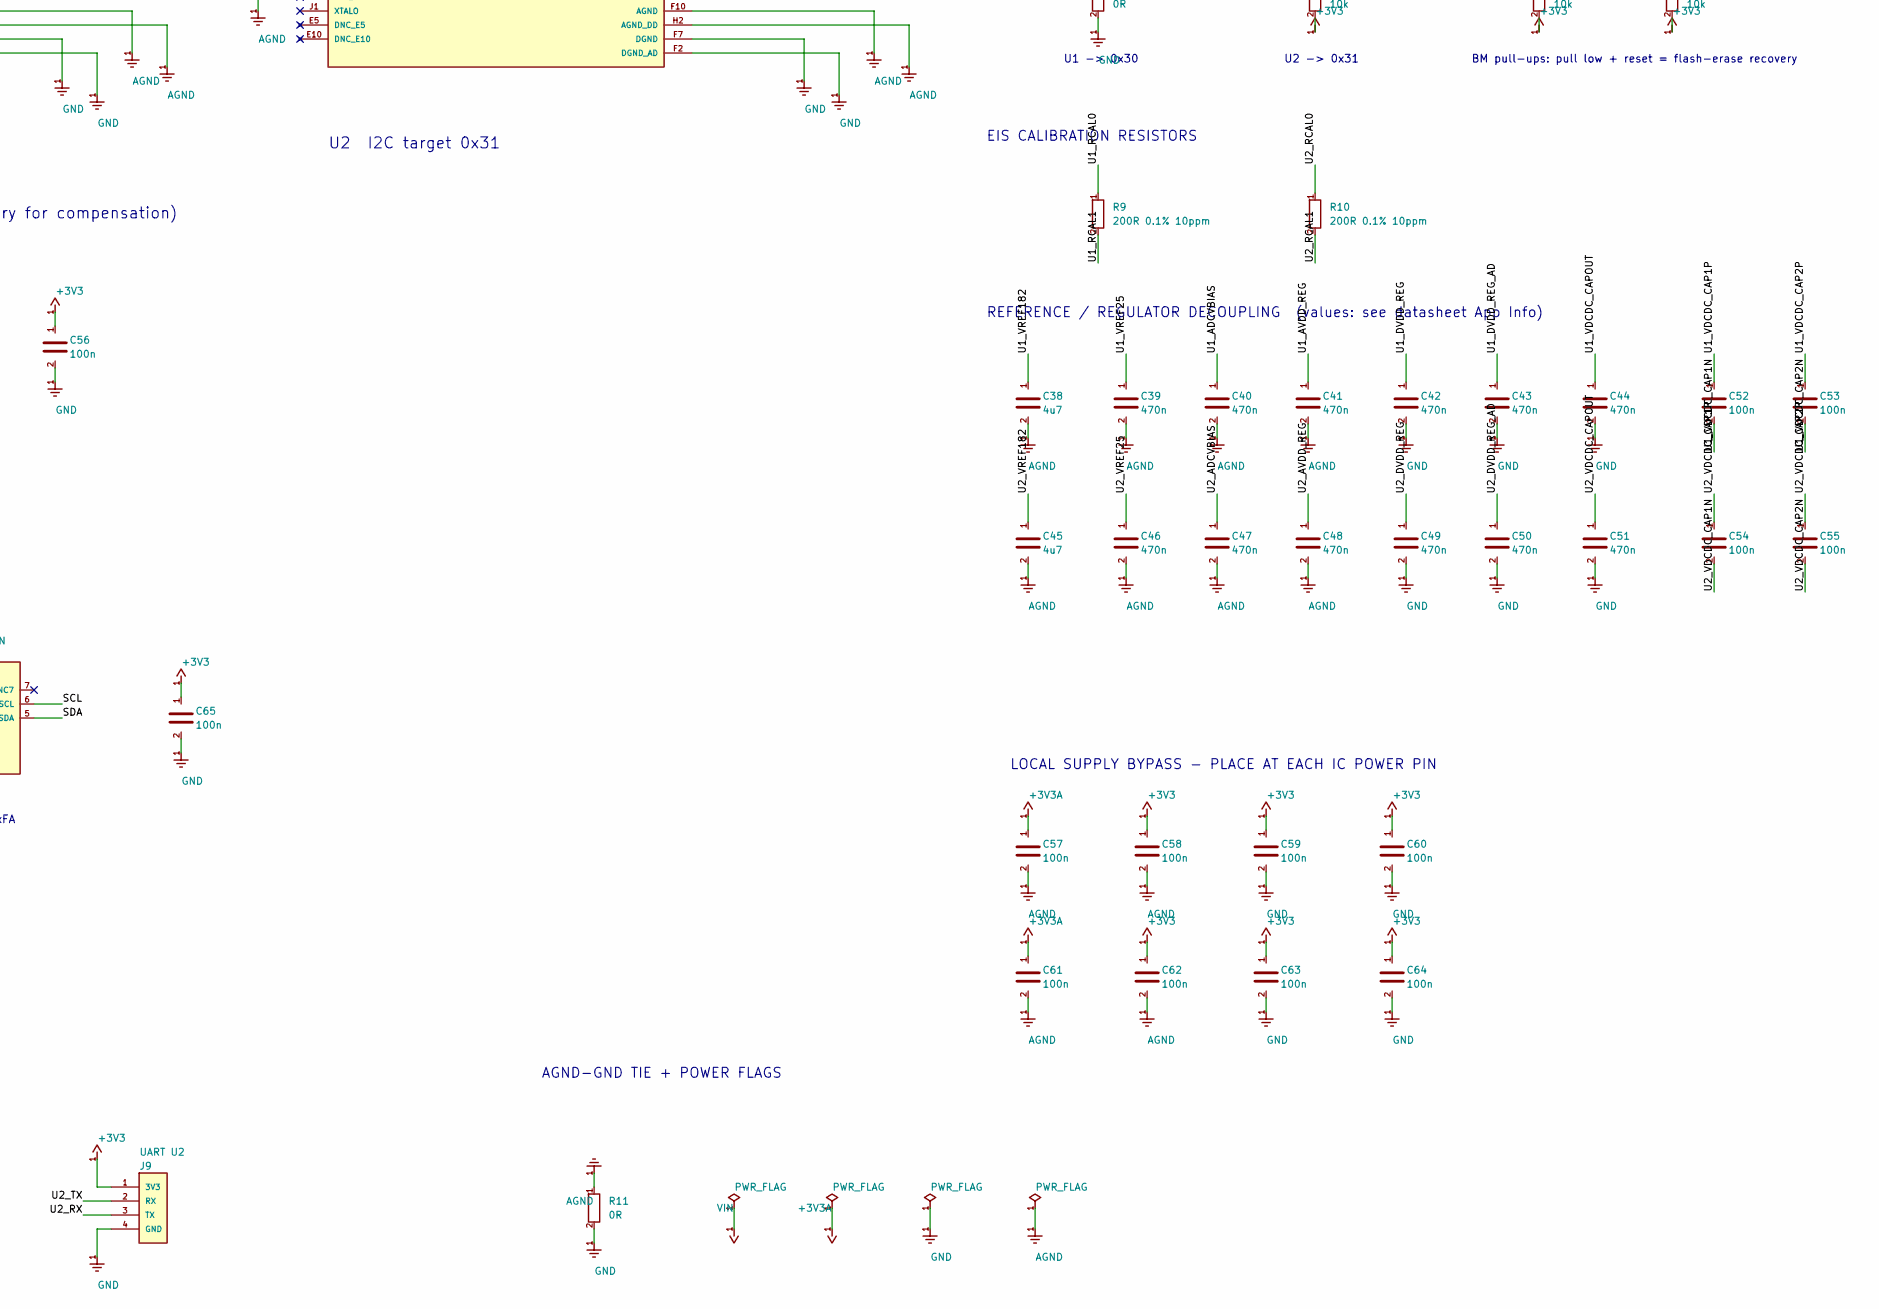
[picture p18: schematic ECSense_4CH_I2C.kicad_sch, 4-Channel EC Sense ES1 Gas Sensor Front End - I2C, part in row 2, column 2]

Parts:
C1, C2, C3, C9, C10, C11, C17, C18, C19, C25, C26, C27: 22p; C_0603_1608Metric
C4, C5, C7, C8, C12, C13, C15, C16, C20, C21, C23, C24, C28, C29, C31, C32, C37, C52, C53, C54, C55, C56, C57, C58, C59, C60, C61, C62, C63, C64, C65: 100n; C_0603_1608Metric
C6, C14, C22, C30, C38, C45: 4u7; C_0603_1608Metric
C33, C34, C36: 10u; C_0603_1608Metric
C35: 1u; C_0603_1608Metric
C39, C40, C41, C42, C43, C44, C46, C47, C48, C49, C50, C51: 470n; C_0603_1608Metric
D1: PESD3V3L2BT; SOT-23
FB1: 600R@100MHz; L_0805_2012Metric
J1: ES1 CH1; EC_Sense_ES1_3pin_2.54mm; MPN 3x Mill-Max 0350 series receptacle (0.3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
J2: ES1 CH2; EC_Sense_ES1_3pin_2.54mm; MPN 3x Mill-Max 0350 series receptacle (0.3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
J3: ES1 CH3; EC_Sense_ES1_3pin_2.54mm; MPN 3x Mill-Max 0350 series receptacle (0.3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
J4: ES1 CH4; EC_Sense_ES1_3pin_2.54mm; MPN 3x Mill-Max 0350 series receptacle (0.3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
J5: Host I2C + power; JST_PH_B6B-PH-K_1x06_P2.00mm_Vertical
J6: SWD U1; PinHeader_1x05_P1.27mm_Vertical
J7: SWD U2; PinHeader_1x05_P1.27mm_Vertical
J8: UART U1; PinHeader_1x04_P2.54mm_Vertical
J9: UART U2; PinHeader_1x04_P2.54mm_Vertical
JP1, JP2, JP3, JP4: SE-RE short; SolderJumper-2_P1.3mm_Open_Pad1.0x1.5mm; not fitted
R1, R2: 2k2; R_0603_1608Metric
R3, R4, R6, R7, R8: 10k; R_0603_1608Metric
R5, R11: 0R; R_0603_1608Metric
R9, R10: 200R 0.1% 10ppm; R_0603_1608Metric
U1, U2: ADuCM355; ADuCM355_LGA-72_6x5mm; MPN ADUCM355BCCZ
U3: ADP151AUJZ-3.3; TSOT-23-5
U4: SHT45-AD1B; Sensirion_DFN-4_1.5x1.5mm_P0.8mm_SHT4x_NoCentralPad
U5: 24AA02E48T-I/SN; SOIC-8_3.9x4.9mm_P1.27mm

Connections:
+3V3: C34.1, C35.1, C56.1, C58.1, C59.1, C60.1, C62.1, C63.1, C64.1, C65.1, FB1.1, J6.1 (VTREF), J7.1 (VTREF), J8.1 (3V3), J9.1 (3V3), R1.1, R2.1, R3.1, R4.1, R6.2, R7.2, R8.2, U1.F1 (DVDD_AD), U1.G2 (AVDD_DD), U1.J6 (DVDD), U2.F1 (DVDD_AD), U2.G2 (AVDD_DD), U2.J6 (DVDD), U3.5 (VOUT), U4.3 (VDD), U5.8 (VCC); also elsewhere on the board
+3V3A: C36.1, C37.1, C57.1, C61.1, FB1.2, U1.F11 (AVDD), U2.F11 (AVDD); also elsewhere on the board
/CH1_CAPPOT: C4.2, U1.C1 (CAP_POT0)
/CH1_CE: C1.1, C4.1, J1.1 (C), U1.B1 (CE0)
/CH1_LPF: C6.1, U1.A4 (AIN4_LPF0)
/CH1_RC0: C5.1, U1.D1 (RC0_0)
/CH1_RC1: C5.2, U1.D2 (RC0_1)
/CH1_RE: C3.1, J1.3 (R), JP1.2 (B), U1.A1 (RE0)
/CH1_SE: C2.1, J1.2 (S), JP1.1 (A), U1.A3 (SE0)
/CH1_VBIAS: C8.1, U1.C2 (VBIAS0)
/CH1_VZERO: C7.1, U1.B2 (VZERO0)
/CH2_CAPPOT: C12.2, U1.C11 (CAP_POT1)
/CH2_CE: C9.1, C12.1, J2.1 (C), U1.B11 (CE1)
/CH2_LPF: C14.1, U1.A8 (AIN7_LPF1)
/CH2_RC0: C13.1, U1.D11 (RC1_0)
/CH2_RC1: C13.2, U1.D10 (RC1_1)
/CH2_RE: C11.1, J2.3 (R), JP2.2 (B), U1.A11 (RE1)
/CH2_SE: C10.1, J2.2 (S), JP2.1 (A), U1.A9 (SE1)
/CH2_VBIAS: C16.1, U1.C10 (VBIAS1)
/CH2_VZERO: C15.1, U1.B10 (VZERO1)
/CH3_CAPPOT: C20.2, U2.C1 (CAP_POT0)
/CH3_CE: C17.1, C20.1, J3.1 (C), U2.B1 (CE0)
/CH3_LPF: C22.1, U2.A4 (AIN4_LPF0)
/CH3_RC0: C21.1, U2.D1 (RC0_0)
/CH3_RC1: C21.2, U2.D2 (RC0_1)
/CH3_RE: C19.1, J3.3 (R), JP3.2 (B), U2.A1 (RE0)
/CH3_SE: C18.1, J3.2 (S), JP3.1 (A), U2.A3 (SE0)
/CH3_VBIAS: C24.1, U2.C2 (VBIAS0)
/CH3_VZERO: C23.1, U2.B2 (VZERO0)
/CH4_CAPPOT: C28.2, U2.C11 (CAP_POT1)
/CH4_CE: C25.1, C28.1, J4.1 (C), U2.B11 (CE1)
/CH4_LPF: C30.1, U2.A8 (AIN7_LPF1)
/CH4_RC0: C29.1, U2.D11 (RC1_0)
/CH4_RC1: C29.2, U2.D10 (RC1_1)
/CH4_RE: C27.1, J4.3 (R), JP4.2 (B), U2.A11 (RE1)
/CH4_SE: C26.1, J4.2 (S), JP4.1 (A), U2.A9 (SE1)
/CH4_VBIAS: C32.1, U2.C10 (VBIAS1)
/CH4_VZERO: C31.1, U2.B10 (VZERO1)
/SCL: D1.2 (IO2), J5.4 (SCL), R2.2, U1.J5 (P0.4/I2C_SCL), U2.J5 (P0.4/I2C_SCL), U4.2 (SCL), U5.6 (SCL); also elsewhere on the board
/SDA: D1.1 (IO1), J5.3 (SDA), R1.2, U1.H5 (P0.5/I2C_SDA), U2.H5 (P0.5/I2C_SDA), U4.1 (SDA), U5.5 (SDA); also elsewhere on the board
/U1_ADCVBIAS: C40.1, U1.E11 (ADCVBIAS_CAP)
/U1_ADDR: R5.1, U1.J4 (P2.4)
/U1_AVDD_REG: C41.1, U1.E1 (AVDD_REG)
/U1_BM: R7.1, U1.D5 (BM/P1.1); also elsewhere on the board
/U1_DVDD_REG: C42.1, U1.J7 (DVDD_REG)
/U1_DVDD_REG_AD: C43.1, U1.G1 (DVDD_REG_AD)
/U1_RCAL0: R9.1, U1.A7 (RCAL0)
/U1_RCAL1: R9.2, U1.A6 (RCAL1)
/U1_RX: J8.3 (TX), U1.J2 (P0.11/UART_SIN)
/U1_SWCLK: J6.3 (SWCLK), U1.H3 (SWCLK)
/U1_SWDIO: J6.2 (SWDIO), U1.H4 (SWDIO)
/U1_TX: J8.2 (RX), U1.J3 (P0.10/UART_SOUT)
/U1_VDCDC_CAP1N: C52.2, U1.J8 (VDCDC_CAP1N)
/U1_VDCDC_CAP1P: C52.1, U1.J9 (VDCDC_CAP1P)
/U1_VDCDC_CAP2N: C53.2, U1.H11 (VDCDC_CAP2N)
/U1_VDCDC_CAP2P: C53.1, U1.G11 (VDCDC_CAP2P)
/U1_VDCDC_CAPOUT: C44.1, U1.J11 (VDCDC_CAPOUT)
/U1_VREF25: C39.1, U1.E2 (VREF_2.5V)
/U1_VREF182: C38.1, U1.A5 (VREF_1.82V)
/U2_ADCVBIAS: C47.1, U2.E11 (ADCVBIAS_CAP)
/U2_ADDR: R6.1, U2.J4 (P2.4)
/U2_AVDD_REG: C48.1, U2.E1 (AVDD_REG)
/U2_BM: R8.1, U2.D5 (BM/P1.1); also elsewhere on the board
/U2_DVDD_REG: C49.1, U2.J7 (DVDD_REG)
/U2_DVDD_REG_AD: C50.1, U2.G1 (DVDD_REG_AD)
/U2_RCAL0: R10.1, U2.A7 (RCAL0)
/U2_RCAL1: R10.2, U2.A6 (RCAL1)
/U2_RX: J9.3 (TX), U2.J2 (P0.11/UART_SIN)
/U2_SWCLK: J7.3 (SWCLK), U2.H3 (SWCLK)
/U2_SWDIO: J7.2 (SWDIO), U2.H4 (SWDIO)
/U2_TX: J9.2 (RX), U2.J3 (P0.10/UART_SOUT)
/U2_VDCDC_CAP1N: C54.2, U2.J8 (VDCDC_CAP1N)
/U2_VDCDC_CAP1P: C54.1, U2.J9 (VDCDC_CAP1P)
/U2_VDCDC_CAP2N: C55.2, U2.H11 (VDCDC_CAP2N)
/U2_VDCDC_CAP2P: C55.1, U2.G11 (VDCDC_CAP2P)
/U2_VDCDC_CAPOUT: C51.1, U2.J11 (VDCDC_CAPOUT)
/U2_VREF25: C46.1, U2.E2 (VREF_2.5V)
/U2_VREF182: C45.1, U2.A5 (VREF_1.82V)
/~ALERT: J5.5 (~ALERT), R3.2, U1.H10 (GPIO1/PWM1), U2.H10 (GPIO1/PWM1)
/~RESET: J5.6 (~RESET), J6.5 (~RESET), J7.5 (~RESET), R4.2, U1.J10 (~RESET), U2.J10 (~RESET)
AGND: C1.2, C2.2, C3.2, C6.2, C7.2, C8.2, C9.2, C10.2, C11.2, C14.2, C15.2, C16.2, C17.2, C18.2, C19.2, C22.2, C23.2, C24.2, C25.2, C26.2, C27.2, C30.2, C31.2, C32.2, C36.2, C37.2, C38.2, C39.2, C40.2, C41.2, C45.2, C46.2, C47.2, C48.2, C57.2, C58.2, C61.2, C62.2, R11.1, U1.B5 (AGND_REF), U1.F10 (AGND), U1.H2 (AGND_DD), U2.B5 (AGND_REF), U2.F10 (AGND), U2.H2 (AGND_DD); also elsewhere on the board
GND: C33.2, C34.2, C35.2, C42.2, C43.2, C44.2, C49.2, C50.2, C51.2, C56.2, C59.2, C60.2, C63.2, C64.2, C65.2, D1.3 (GND), J5.2 (GND), J6.4 (GND), J7.4 (GND), J8.4 (GND), J9.4 (GND), R5.2, R11.2, U1.F2 (DGND_AD), U1.F7 (DGND), U2.F2 (DGND_AD), U2.F7 (DGND), U3.2 (GND), U4.4 (VSS), U5.4 (VSS); also elsewhere on the board
VIN: C33.1, J5.1 (VIN), U3.1 (VIN), U3.3 (EN); also elsewhere on the board

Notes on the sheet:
EIS CALIBRATION RESISTORS
CHANNEL 1 (U1 potentiostat 0)
AGND-GND TIE + POWER FLAGS
addr 0x44
CHANNEL 3 (U2 potentiostat 0)
U2 I2C target 0x31
addr 0x50, EUI-48 at 0xFA
4-CHANNEL EC SENSE ES1 ELECTROCHEMICAL GAS SENSOR FRONT END - SINGLE I2C BUS OUTPUT
U1 -> 0x30
DEBUG / PROGRAMMING
Analog rail: ferrite-isolated from +3V3
U2 -> 0x31
BM pull-ups: pull low + reset = flash-erase recovery
AMBIENT T / RH (mandatory for compensation)
REFERENCE / REGULATOR DECOUPLING (values: see datasheet App Info)
POWER
BOARD ID / CAL STORE
2 x ADuCM355 dual potentiostat, each an I2C target (U1=0x30, U2=0x31). Programmable bias per channel.
LOCAL SUPPLY BYPASS - PLACE AT EACH IC POWER PIN
I2C ADDRESS STRAPS (read on P2.4 at boot)
CHANNEL 2 (U1 potentiostat 1)
CHANNEL 4 (U2 potentiostat 1)
U1 I2C target 0x30
I2C BUS
REV B - PCB / ASSEMBLY NOTES 1. Pinout and decoupling corrected to ADuCM355 Rev C. Board: 120 x 80 mm, 4 layers. 2. All capacitors fitted. JP1-JP4 stay OPEN during operation; R11 (0 ohm) must be fitted. 3. Sensor sockets: 3 x Mill-Max 0548-0-15-15-21-27-10-0 per ES1, 1.0 mm finished PTH. PCB top-vi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
DESIGN NOTES RTIA selection (ADuCM355 LPTIA, programmable 1k...512k): ES1-AG1-200 : 40 nA/ppm, 200 ppm FS -> 8 uA FS. RTIA = 100k -> 0.80 V FS. 16-bit ADC over ~+/-0.9 V -> ~27 uV LSB -> 0.27 nA -> ~0.007 ppm/LSB. ES1-AG1-10 : 40 nA/ppm, 10 ppm FS -> 400 nA FS. RTIA = 512k -> 0.205 V FS -> ~0.0013 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

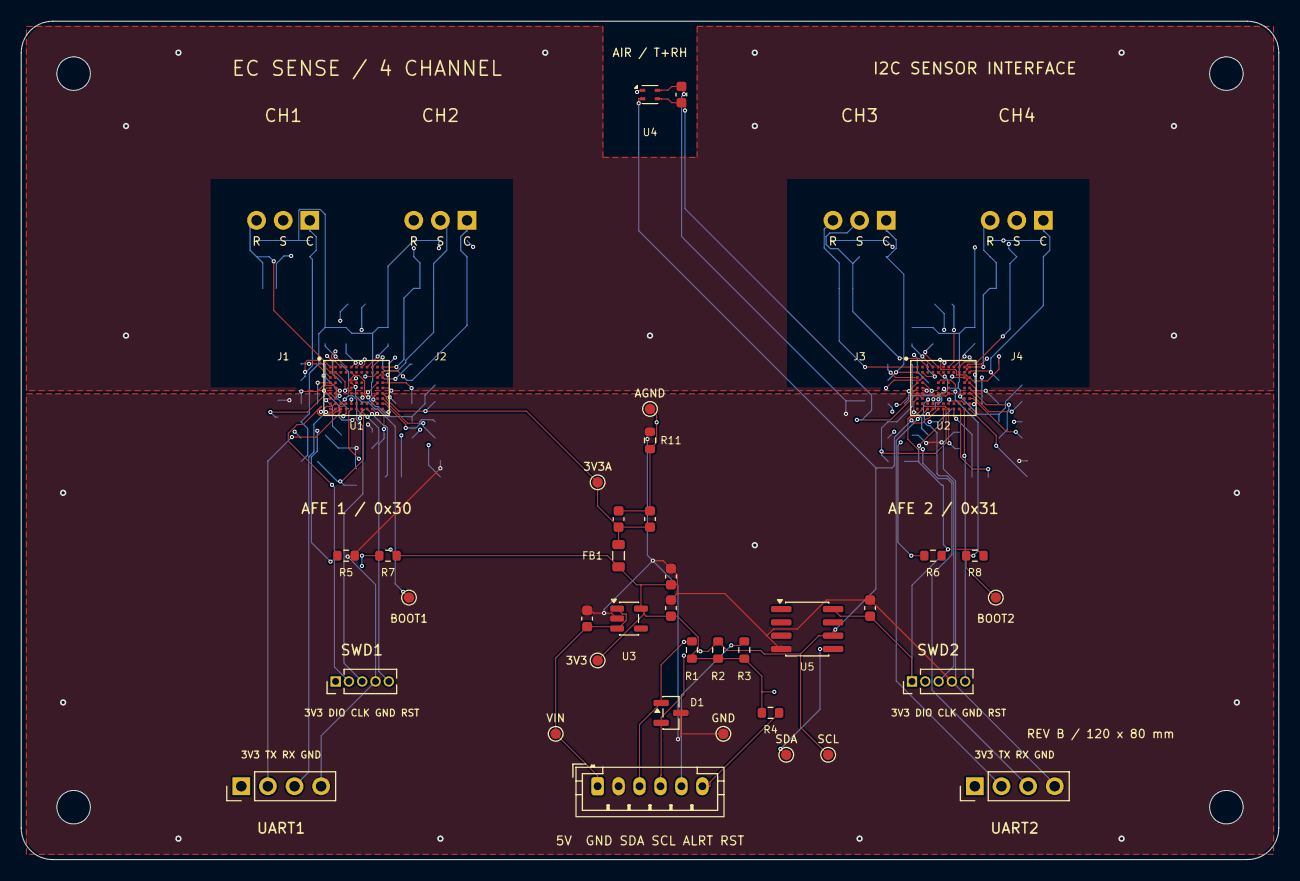
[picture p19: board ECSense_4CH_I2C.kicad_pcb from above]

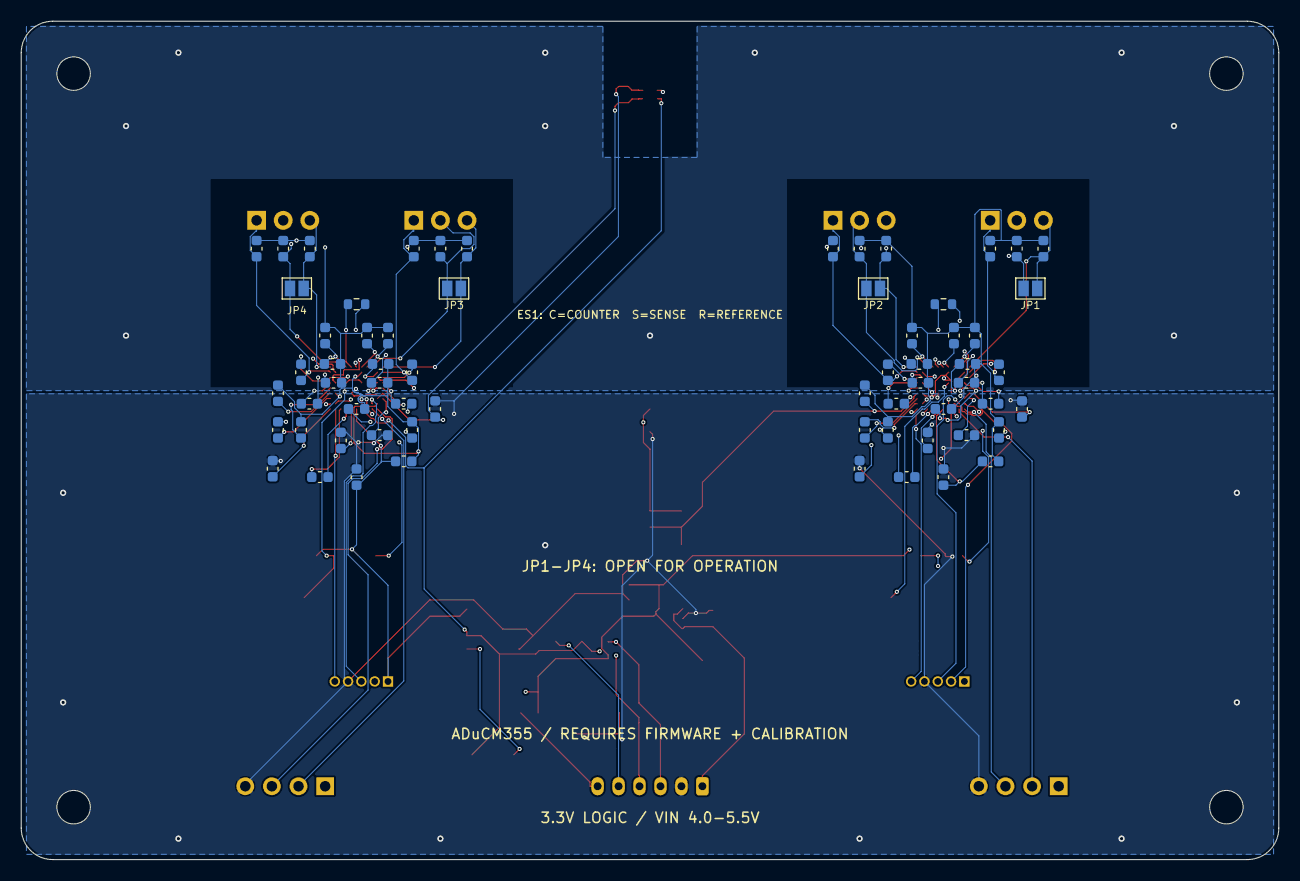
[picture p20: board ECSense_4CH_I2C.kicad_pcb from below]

Board: 4 copper layers, 120.0 x 80.0 mm, 109 parts (64 on the bottom side), 83 nets.

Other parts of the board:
H1, H2, H3, H4: M3; MountingHole_3.2mm_M3
TP1: VIN; TestPoint_Pad_D1.0mm
TP2: 3V3; TestPoint_Pad_D1.0mm
TP3: 3V3A; TestPoint_Pad_D1.0mm
TP4: GND; TestPoint_Pad_D1.0mm
TP5: AGND; TestPoint_Pad_D1.0mm
TP6: BOOT1; TestPoint_Pad_D1.0mm
TP7: BOOT2; TestPoint_Pad_D1.0mm
TP8: SDA; TestPoint_Pad_D1.0mm
TP9: SCL; TestPoint_Pad_D1.0mm

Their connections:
+3V3: TP2.1; also elsewhere on the board
+3V3A: TP3.1; also elsewhere on the board
/SCL: TP9.1; also elsewhere on the board
/SDA: TP8.1; also elsewhere on the board
/U1_BM: TP6.1; also elsewhere on the board
/U2_BM: TP7.1; also elsewhere on the board
AGND: TP5.1; also elsewhere on the board
GND: TP4.1; also elsewhere on the board
VIN: TP1.1; also elsewhere on the board

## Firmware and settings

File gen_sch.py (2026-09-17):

#!/usr/bin/env python3
"""
Generate a KiCad 9 schematic for a 4-channel EC Sense ES1 electrochemical
gas-sensor front end with a single I2C output bus.

Topology: 2 x ADuCM355 (dual potentiostat each) -> 4 sensor channels.
Both ADuCM355 act as I2C targets on one shared bus (addresses strapped on P2.4).

Connections are made by NET LABELS (no long wires) so the sheet stays readable.
"""
import uuid as _uuid

def U():
    return str(_uuid.uuid4())

PAPER = "A1"          # 841 x 594 mm
LIB = "ECGAS"

# ---------------------------------------------------------------- primitives
def esc(s):
    # KiCad's s-expression parser rejects raw newlines inside quoted strings
    return (s.replace('\\', '\\\\')
             .replace('"', '\\"')
             .replace('\r\n', '\\n')
             .replace('\n', '\\n'))

def prop(name, value, x, y, rot=0, hide=False, size=1.27, justify=None):
    e = f'(font (size {size} {size}))'
    if justify:
        e = f'(font (size {size} {size})) (justify {justify})'
    h = " hide" if hide else ""
    return (f'(property "{esc(name)}" "{esc(value)}" (at {x} {y} {rot}) '
            f'(effects {e}{h}))')

def pin(etype, shape, x, y, rot, length, name, number, nsize=1.0, numsize=1.0):
    return (f'(pin {etype} {shape} (at {x} {y} {rot}) (length {length})\n'
            f'  (name "{esc(name)}" (effects (font (size {nsize} {nsize}))))\n'
            f'  (number "{esc(number)}" (effects (font (size {numsize} {numsize}))))\n'
            f')')

def rect(x1, y1, x2, y2, fill="background"):
    return (f'(rectangle (start {x1} {y1}) (end {x2} {y2}) '
            f'(stroke (width 0.254) (type default)) (fill (type {fill})))')

# ---------------------------------------------------------------- symbol defs
SYMBOLS = {}

def add_symbol(name, ref, value, pins, body, extra_props=None, ref_at=(0,0),
               val_at=(0,-2.54), power=False, hide_pin_names=False,
               pin_name_offset=1.016):
    """pins: list of dicts with etype, shape, x, y, rot, length, name, number"""
    SYMBOLS[name] = dict(ref=ref, value=value, pins=pins, body=body,
                         extra=extra_props or {}, ref_at=ref_at, val_at=val_at,
                         power=power, hide_names=hide_pin_names,
                         offset=pin_name_offset)

def sym_text(name):
    s = SYMBOLS[name]
    out = [f'(symbol "{LIB}:{name}"']
    out.append(f'  (pin_names (offset {s["offset"]})' + (' hide' if s["hide_names"] else '') + ')')
    out.append('  (in_bom yes) (on_board yes)')
    if s["power"]:
        out.append('  (power)')
    out.append('  ' + prop("Reference", s["ref"], s["ref_at"][0], s["ref_at"][1],
                           hide=s["power"], justify="left"))
    out.append('  ' + prop("Value", s["value"], s["val_at"][0], s["val_at"][1], justify="left"))
    out.append('  ' + prop("Footprint", s["extra"].get("Footprint", ""), 0, 0, hide=True))
    out.append('  ' + prop("Datasheet", s["extra"].get("Datasheet", ""), 0, 0, hide=True))
    out.append('  ' + prop("Description", s["extra"].get("Description", ""), 0, 0, hide=True))
    for k, v in s["extra"].items():
        if k in ("Footprint", "Datasheet", "Description"):
            continue
        out.append('  ' + prop(k, v, 0, 0, hide=True))
    out.append(f'  (symbol "{name}_0_1"')
    for b in s["body"]:
        out.append('    ' + b)
    out.append('  )')
    out.append(f'  (symbol "{name}_1_1"')
    for p in s["pins"]:
        out.append('    ' + pin(**p).replace('\n', '\n    '))
    out.append('  )')
    out.append(')')
    return '\n'.join(out)
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

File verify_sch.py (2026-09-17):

#!/usr/bin/env python3
"""Structural / electrical sanity check on the generated .kicad_sch."""
import sexpdata, collections, sys, math

S = sexpdata.Symbol
d = sexpdata.loads(open("ECSense_4CH_I2C.kicad_sch").read())

def name(x):
    return str(x[0]) if isinstance(x, list) and x else None

def find(node, tag):
    return [c for c in node if isinstance(c, list) and name(c) == tag]

def get(node, tag):
    r = find(node, tag)
    return r[0] if r else None

# ---------- gather lib symbols
libs = {}
for sym in find(get(d, "lib_symbols"), "symbol"):
    lid = str(sym[1])
    pins = []
    for sub in find(sym, "symbol"):
        for p in find(sub, "pin"):
            at = get(p, "at")
            num = str(get(p, "number")[1])
            pins.append((num, float(at[1]), float(at[2]), float(at[3])))
    libs[lid] = pins

# ---------- placed symbols
refs = collections.Counter()
pin_points = collections.defaultdict(list)   # (x,y) -> [ref.pin]
for sym in d:
    if not (isinstance(sym, list) and name(sym) == "symbol"):
        continue
    lid = str(get(sym, "lib_id")[1])
    at = get(sym, "at")
    x, y, rot = float(at[1]), float(at[2]), float(at[3])
    ref = None
    for p in find(sym, "property"):
        if str(p[1]) == "Reference":
            ref = str(p[2])
    refs[ref] += 1
    for num, px, py, prot in libs[lid]:
        if rot == 90:   px, py = -py, px
        elif rot == 180: px, py = -px, -py
        elif rot == 270: px, py = py, -px
        pin_points[(round(x + px, 3), round(y - py, 3))].append(f"{ref}.{num}")

dups = {r: c for r, c in refs.items() if c > 1}
print("duplicate refdes:", dups if dups else "none")

# ---------- wires (union-find over endpoints)
parent = {}
def froot(a):
    parent.setdefault(a, a)
    while parent[a] != a:
        parent[a] = parent[parent[a]]; a = parent[a]
    return a
def union(a, b):
    ra, rb = froot(a), froot(b)
    if ra != rb: parent[ra] = rb

wires = []
for w in find(d, "wire"):
    pts = get(w, "pts")
    a = (round(float(pts[1][1]), 3), round(float(pts[1][2]), 3))
    b = (round(float(pts[2][1]), 3), round(float(pts[2][2]), 3))
    wires.append((a, b)); union(a, b)

# ---------- labels
labels = collections.defaultdict(list)
for tag in ("label", "global_label", "hierarchical_label"):
    for l in find(d, tag):
        at = get(l, "at")
        pt = (round(float(at[1]), 3), round(float(at[2]), 3))
        labels[str(l[1])].append(pt)

ncs = set()
for n in find(d, "no_connect"):
    at = get(n, "at")
    ncs.add((round(float(at[1]), 3), round(float(at[2]), 3)))

# nodes = wire endpoints ∪ pin points ∪ label points
allpts = set()
for a, b in wires: allpts.add(a); allpts.add(b)
allpts |= set(pin_points) | {p for v in labels.values() for p in v} | ncs
for p in allpts: froot(p)

# ---------- T-junctions: KiCad connects a point that lies in the INTERIOR of a wire
def on_segment(p, a, b):
    (px, py), (ax, ay), (bx, by) = p, a, b
    if p == a or p == b:
        return False
    cross = (bx - ax) * (py - ay) - (by - ay) * (px - ax)
    if abs(cross) > 1e-6:
        return False
    dot = (px - ax) * (bx - ax) + (py - ay) * (by - ay)
    if dot < 0:
        return False
    return dot <= (bx - ax) ** 2 + (by - ay) ** 2

tee = 0
for a, b in wires:
    for p in allpts:
        if on_segment(p, a, b):
            union(p, a); tee += 1
print(f"T-junctions (point on wire interior): {tee}")

# ---------- build nets
net_of = {}
for p in allpts:
    net_of.setdefault(froot(p), set()).add(p)

# join all points that carry the same label name
for nm, pts in labels.items():
    for p in pts[1:]:
        union(pts[0], p)

net_of = {}
for p in allpts:
    net_of.setdefault(froot(p), set()).add(p)

netname = {}
for nm, pts in labels.items():
    for p in pts:
        netname.setdefault(froot(p), set()).add(nm)

problems = []

# label conflicts (two different names on same electrical node)
for root, names in netname.items():
    if len(names) > 1:
        problems.append(f"NET MERGE: node has labels {sorted(names)}")

# dangling labels (label not on a wire endpoint)
wire_ends = set()
for a, b in wires: wire_ends.add(a); wire_ends.add(b)
for nm, pts in labels.items():
    for p in pts:
        if p not in wire_ends and p not in pin_points:
            problems.append(f"DANGLING LABEL {nm} at {p}")

# pins not connected to a wire, a label, or a no-connect
for p, names in pin_points.items():
    if p in ncs: continue
    if p in wire_ends: continue
    if any(p in v for v in labels.values()): continue
    if len(names) > 1: continue           # pin-to-pin direct
    problems.append(f"UNCONNECTED PIN {names} at {p}")

# wire endpoints that touch nothing
for p in wire_ends:
    if p in pin_points: continue
    if any(p in v for v in labels.values()): continue
    if sum(1 for a, b in wires if a == p or b == p) > 1: continue
    problems.append(f"DANGLING WIRE END at {p}")

# single-pin nets (by label name)
conn_count = collections.Counter()
for p, names in pin_points.items():
    conn_count[froot(p)] += len(names)
for root, names in netname.items():
    if conn_count.get(root, 0) < 2:
        problems.append(f"SINGLE-PIN NET {sorted(names)} ({conn_count.get(root,0)} pin(s))")

# off-grid check (1.27 mm)
for p in allpts:
    for c in p:
        if abs(round(c / 1.27) * 1.27 - c) > 1e-3:
            problems.append(f"OFF-GRID point {p}")
            break

print(f"\nsymbols placed: {sum(refs.values())}   distinct nets: {len(net_of)}")
print(f"named nets: {len(netname)}")
if problems:
    print(f"\n{len(problems)} issue(s):")
    for p in sorted(set(problems))[:80]:
        print("  -", p)
else:
    print("\nno structural issues found.")

# net summary
print("\n--- net pin counts ---")
rows = []
for root, names in netname.items():
    rows.append((sorted(names)[0], conn_count.get(root, 0)))
for nm, c in sorted(rows):
    print(f"  {nm:24s} {c}")
